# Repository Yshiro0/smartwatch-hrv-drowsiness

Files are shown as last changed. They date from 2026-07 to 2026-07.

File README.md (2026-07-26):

# ESP32-C3 SmartWatch — HR / HRV / Drowsiness Monitor

A wrist-worn drowsiness-detection smartwatch built on the ESP32-C3, paired over BLE with a companion Android app that handles GPS tracking and alerts. Designed as a low-cost fatigue monitor for drivers, students, and shift workers.

  

---

## Overview

The watch continuously reads heart rate, heart-rate variability (HRV), and wrist tilt, then computes a live **0–100 drowsiness score** on-device. Sensor data streams over Bluetooth Low Energy to a phone app every 500 ms; the phone owns GPS/speed and fires a vibration + alarm whenever the score crosses a drowsy threshold.

```
┌─────────────────────────┐        BLE (GATT)        ┌──────────────────────────┐
│   ESP32-C3 Watch         │ ───── sensor JSON ────►  │   Android App             │
│                          │        every 500ms        │                          │
│ • MAX30102 (HR/HRV)      │ ◄──── lat,lng,speed ────  │ • FusedLocationProvider   │
│ • MPU6050 (tilt)         │                            │ • Vibration + alarm       │
│ • GC9A01 round display   │                            │ • Live dashboard UI       │
└─────────────────────────┘                            └──────────────────────────┘
```

**Design decision:** GPS, vibration, and sound alerts live on the *phone*, not the watch. The watch's only job is to sense and stream — this keeps the firmware simple and avoids needing a GPS module or buzzer on the wrist unit.

---

## Features

- Real-time BPM display with animated heartbeat icon and live ECG/PPG-style waveform strip
- HRV (SDNN) computed from the last 8 RR intervals
- Wrist tilt angle from accelerometer, used as a head-drop / posture-change proxy
- Weighted, multi-signal drowsiness score (0–100) with a 3-minute personal calibration phase
- BLE GATT server on the watch — auto re-advertises on disconnect
- Android dashboard: BPM, HRV (with qualitative label), drowsiness %, tilt, GPS lat/lng, speed, calibration progress, alert history
- Drowsiness alert: vibration pattern + alarm tone + toast, with a 15-second cooldown to avoid alert spam
- Finger-presence detection to avoid false readings when the watch isn't worn

---

## Hardware

| Component | Part | Interface |
|---|---|---|
| MCU | ESP32-C3 Super Mini | — |
| Display | GC9A01, 240×240 round SPI | SPI |
| Heart rate / SpO₂ sensor | MAX30102 | I2C (0x57) |
| IMU (tilt) | MPU6050 | I2C (0x68) |

### Wiring

**Display (GC9A01):**

| Display Pin | ESP32-C3 GPIO |
|---|---|
| SCK | GPIO 2 |
| MOSI (SDA) | GPIO 4 |
| CS | GPIO 5 |
| DC | GPIO 1 |
| RST | GPIO 0 |
| BLK | 3.3V (**must be tied high — screen stays blank otherwise**) |

**I2C bus (shared by MAX30102 + MPU6050):**

| Signal | ESP32-C3 GPIO |
|---|---|
| SDA | GPIO 6 |
| SCL | GPIO 7 |

MPU6050's `AD0` pin is tied to GND (address `0x68`). GPIO8/GPIO9 are avoided for I2C since they're strapping pins that can prevent boot if pulled low at startup.

Run the I2C scanner in `firmware/WIRING.md` first — you should see both `0x57` and `0x68` before flashing the main sketch.

---

## Firmware

**Stack:** Arduino IDE (C++) · [Arduino_GFX_Library](https://github.com/moononournation/Arduino_GFX) · SparkFun MAX3010x library · raw I2C driver for MPU6050 · ESP32 BLE Arduino (GATT server)

**Board:** `ESP32C3 Dev Module` or `Nologo ESP32C3 Super Mini`

### Signal processing

- **Beat detection:** adaptive-threshold, rising-edge-only detection on the MAX30102 IR channel (SparkFun `checkForBeat`), gated to accept RR intervals between 400–1500 ms to reject noise
- **HRV (SDNN):** standard deviation of the last 8 RR intervals — the classic time-domain HRV metric
- **Tilt angle:** `θ = arccos(az / |a|)`, where `|a| = sqrt(ax² + ay² + az²)` — the angle between the wrist's Z-axis and vertical
- **Drowsiness score (0–100):** a weighted sum of three components, recomputed every 500 ms once calibration is done:
  - up to **50 pts** for HRV dropping below the personal baseline
  - up to **30 pts** for tilt deviating from the baseline posture (scaled over a 15° range)
  - up to **20 pts** for BPM dropping below 65 (scaled over a 20 bpm–65 bpm range)
- **Calibration:** a 3-minute warm-up on boot averages SDNN and tilt while the wearer is alert and seated, establishing `baselineSDNN` and `baselineTilt` for the scoring formulas above

A full derivation of these formulas, plus expected margin-of-error tables, is in [`docs/HRV_Tilt_Drowsiness_Reference.pdf`](docs/HRV_Tilt_Drowsiness_Reference.pdf).

### Required libraries (Arduino Library Manager)

- `Arduino_GFX_Library` (moononournation)
- `SparkFun MAX3010x Pulse and Proximity Sensor Library`
- `ESP32 BLE Arduino` (bundled with the ESP32 board package)

### Uploading

If the COM port doesn't show up or upload fails: hold **BOOT**, tap **RST**, release **BOOT**, then click Upload.

---

## BLE protocol

The watch advertises as `SmartWatch` and runs a single GATT service:

```
Service UUID:       12345678-1234-1234-1234-123456789abc
Sensor Char UUID:   12345678-1234-1234-1234-123456789abd   Notify · watch → phone
Location Char UUID: 12345678-1234-1234-1234-123456789abe   Write  · phone → watch
```

**Watch → phone** (JSON, sent every 500 ms):

```json
{"b":72,"h":42.1,"d":35.0,"t":8.2,"c":1,"f":1}
```

| Field | Meaning | Type |
|---|---|---|
| `b` | Heart rate (BPM) | int |
| `h` | HRV / SDNN (ms) | float |
| `d` | Drowsiness score (0–100) | float |
| `t` | Tilt angle (degrees) | float |
| `c` | Calibration complete (0/1) | int |
| `f` | Finger detected on sensor (0/1) | int |

**Phone → watch** (plain CSV string, sent on every location update):

```
<lat>,<lng>,<speed_kmh>
```

e.g. `14.083200,121.145600,42.3` — parsed on the watch by splitting on the first and last comma.

---

## Android app

**Stack:** Android Studio, Kotlin, BLE GATT client, Google Play Services `FusedLocationProviderClient`, `minSdk 26` / `targetSdk 34`

**What it does:**
- Scans for and connects to the `SmartWatch` BLE device, subscribes to sensor notifications
- Renders BPM, HRV (with a qualitative label — Very Low / Low / Moderate / Normal / Excellent), drowsiness % with color-coded state (AWAKE / ALERT / DROWSY), tilt, and calibration progress
- Streams GPS lat/lng/speed via `FusedLocationProviderClient` (1s interval, high accuracy) and writes it back to the watch's Location characteristic
- Fires a **vibration pattern + alarm ringtone + toast** when drowsiness score ≥ 70% *and* the finger sensor confirms the watch is being worn, with a 15-second cooldown between alerts
- Tracks alert count and last-alert timestamp for the session

**Permissions required:** `BLUETOOTH_SCAN`, `BLUETOOTH_CONNECT` (Android 12+), `ACCESS_FINE_LOCATION`, `ACCESS_COARSE_LOCATION`, `VIBRATE`.

---

## 3D-printed case & strap

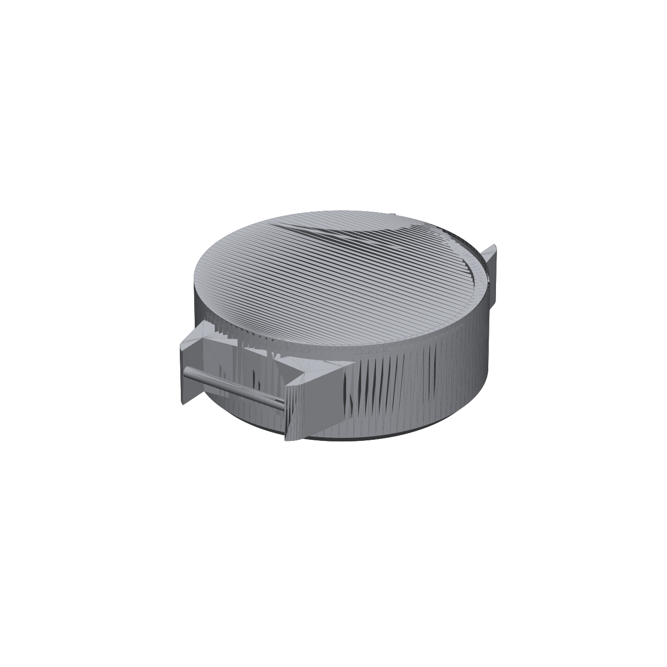
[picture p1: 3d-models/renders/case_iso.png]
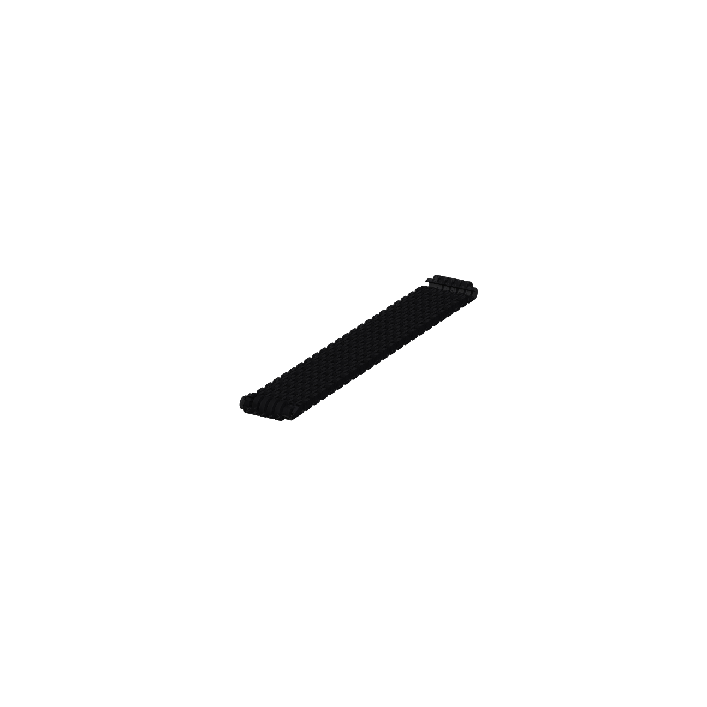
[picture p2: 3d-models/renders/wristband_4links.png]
 

A printable enclosure and modular link wristband are included in [`3d-models/`](3d-models/), along with preview renders and approximate dimensions for each part. See [`3d-models/README.md`](3d-models/README.md) for details.

---

## Getting started

1. Wire up the hardware per the [Hardware](#hardware) section above.
2. Open `firmware/smartwatch.ino` in Arduino IDE, install the required libraries, select the ESP32-C3 board, and flash.
3. Confirm over Serial Monitor (115200 baud) that both `MAX30102 OK` and `MPU6050 OK` print, and that BLE begins advertising as `SmartWatch`.
4. Open `android_app/` in Android Studio, build, and install on a phone running Android 8.0 (API 26) or later — or skip building it yourself and install the pre-built [`releases/app-debug.apk`](releases/app-debug.apk) directly (debug build, so you'll need to allow installs from unknown sources / sideloading).
5. Launch the app, grant Bluetooth + Location permissions, and tap **SCAN** to connect.
6. Wear the watch and hold still for the 3-minute calibration countdown shown on both the watch display and the app before relying on the drowsiness score.

---

## Repository structure

```
.
├── firmware/
│   ├── smartwatch.ino       # Full ESP32-C3 sketch — sensors, display, BLE, algorithms
│   └── WIRING.md            # Pin reference, library list, I2C scanner sketch
├── android_app/
│   └── app/
│       ├── src/main/java/.../MainActivity.kt   # BLE client, GPS, alerts, dashboard logic
│       ├── src/main/res/                        # Layouts, colors, drawables
│       └── build.gradle
├── docs/
│   └── HRV_Tilt_Drowsiness_Reference.pdf   # Formulas, algorithm derivation, error margins
├── releases/
│   └── app-debug.apk                       # Pre-built debug APK, ready to sideload
└── 3d-models/
    ├── watchcase_new.3mf                              # Printable case assembly
    ├── prizma_wristband_144mm_plus4links.stl           # Wristband, larger size
    ├── prizma_wristband_144mm_plus2links.stl           # Wristband, smaller size
    └── renders/                                        # Preview images of the above
```

---

## Known limitations / roadmap

- Drowsiness weighting (50/30/20) was chosen heuristically, not validated against a labeled dataset — treat scores as a relative fatigue indicator, not a clinical measurement
- No on-watch alerting means the wearer relies entirely on the phone being nearby and connected
- Single BLE connection only — no reconnection to a specific phone if multiple are in range
- SDNN over only 8 RR intervals is a short window; longer buffers would give a more stable HRV estimate at the cost of slower response to changes

## License

Add a license of your choice here (MIT is a common default for hobby hardware/firmware projects like this).

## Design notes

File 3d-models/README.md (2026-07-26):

# 3D-Printed Case & Strap

Printable enclosure and wristband for the ESP32-C3 SmartWatch build.

| File | Description | Approx. size (W × L × H, mm) |
|---|---|---|
| [`watchcase_new.3mf`](watchcase_new.3mf) | Watch case assembly — main shell, bezel, and strap lugs | 64 × 80 × 24 |
| [`prizma_wristband_144mm_plus4links.stl`](prizma_wristband_144mm_plus4links.stl) | Modular link wristband, 144mm base + 4 extra links (larger wrist) | 26 × 183 × 8.3 |
| [`prizma_wristband_144mm_plus2links.stl`](prizma_wristband_144mm_plus2links.stl) | Modular link wristband, 144mm base + 2 extra links (smaller wrist) | 26 × 169 × 8.3 |

Dimensions above are bounding-box measurements taken directly from the model files — treat them as a sanity check for build-plate/bed size, not a substitute for checking the actual model in your slicer.

## Case

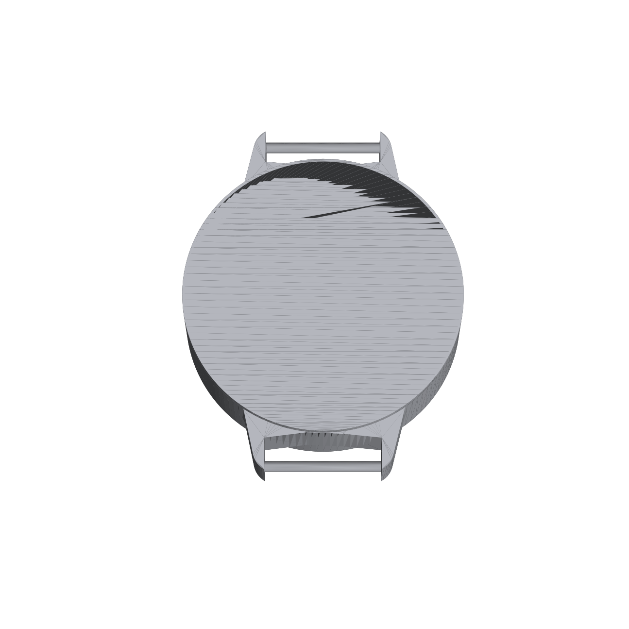
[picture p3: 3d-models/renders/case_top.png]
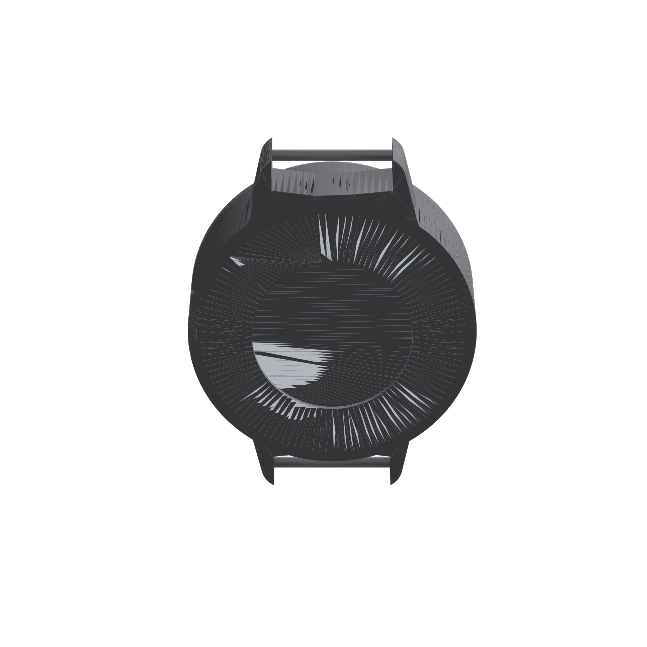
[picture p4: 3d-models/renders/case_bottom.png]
  

Houses the ESP32-C3 Super Mini, GC9A01 round display, MAX30102, and MPU6050 as a single wrist-worn unit. `watchcase_new.3mf` contains the full multi-body assembly (shell + bezel + button/lug details) with parts already positioned — most slicers will preserve the layout on import.

## Wristband

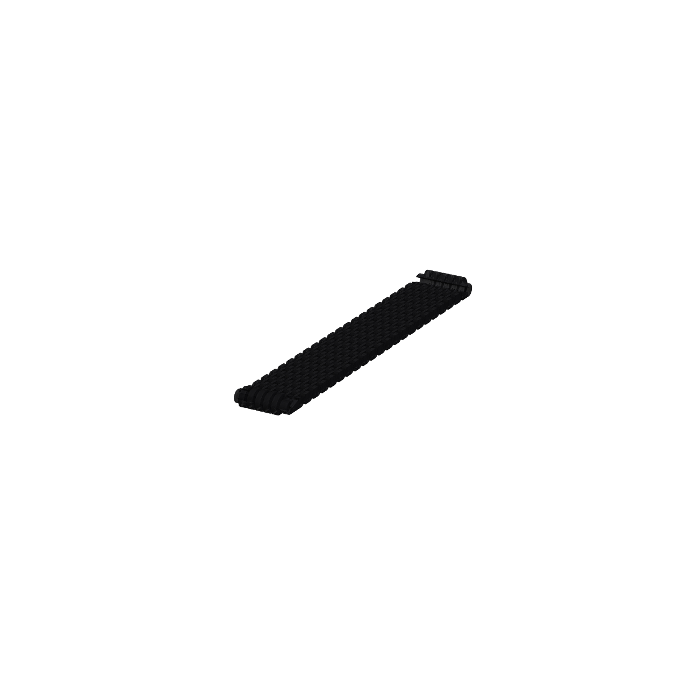
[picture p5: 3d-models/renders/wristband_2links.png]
 

Modular, link-style band that attaches to the case lugs. Two link-count variants are provided so you can pick the closer fit for your wrist size, rather than needing a separate buckle/adjustment mechanism.

## Notes

- Renders above are auto-generated flat-shaded previews for a quick visual reference — they're not a substitute for opening the files in your slicer to check wall thickness, supports, and orientation.
- Recommended print settings (material, layer height, infill, supports) aren't documented yet — add them here once you've dialed in your printer profile.

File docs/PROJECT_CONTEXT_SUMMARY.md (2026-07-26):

# SmartWatch Project — Context Summary

Paste this as your first message in the new account to bring Claude up to speed.

## Project: ESP32-C3 Smartwatch (Heart Rate + HRV + Drowsiness + GPS)

### Hardware
- ESP32-C3 Super Mini (MCU)
- GC9A01 240×240 round SPI display — DC=GPIO1, CS=GPIO5, SCK=GPIO2, MOSI=GPIO4, RST=GPIO0, BLK→3.3V
- MAX30102 (heart rate/HRV) — I2C, SDA=GPIO6, SCL=GPIO7, addr 0x57
- MPU6050 (accel/gyro, tilt) — I2C same bus, addr 0x68

### Firmware stack
Arduino IDE, C++, Arduino_GFX_Library, SparkFun MAX3010x library,
raw I2C for MPU6050, ESP32 BLE Arduino (GATT server)

### Key algorithms implemented
- Median filter + IIR low-pass on heart signal
- Adaptive threshold beat detection (envelope tracking, rising-edge only)
- SDNN (HRV) from last 8 RR intervals
- Tilt angle via arccos(az/|a|) from accelerometer
- Weighted drowsiness score: HRV drop (50pts) + tilt deviation (30pts) + low BPM (20pts) = 0–100 score
- 3-minute calibration phase to set personal baseline SDNN/tilt

### Design decision
GPS, vibration, and sound alerts moved OFF the watch — phone handles these
via BLE instead (watch just streams sensor data, phone does alerts + GPS).

### Mobile app
Android Studio, Kotlin, BLE GATT client, Google Play Services
FusedLocationProviderClient for GPS, min SDK 26. App shows BPM/HRV/drowsiness/
tilt/GPS/speed dashboard and triggers vibrate+alarm when drowsiness >= 70%.

### BLE contract
```
Service UUID:       12345678-1234-1234-1234-123456789abc
Sensor Char UUID:   12345678-1234-1234-1234-123456789abd  (Notify, watch->phone)
Location Char UUID: 12345678-1234-1234-1234-123456789abe  (Write, phone->watch)
```

JSON payload sent from watch to phone every 500ms:
```json
{"b":72,"h":42.1,"d":35.0,"t":8.2,"c":1,"f":1}
```
- b = BPM
- h = HRV (SDNN in ms)
- d = drowsiness score (0-100)
- t = tilt angle (degrees)
- c = calibrated (0/1)
- f = finger detected (0/1)

### Deliverables already created (included in this export)
- `firmware/smartwatch.ino` — full working ESP32-C3 sketch
- `firmware/WIRING.md` — pin reference and required libraries
- `android_app/` — full Android Studio Kotlin project (MainActivity.kt,
  layouts, manifest, gradle files)
- `docs/HRV_Tilt_Drowsiness_Reference.pdf` — technical reference covering
  HRV formulas, tilt formula, drowsiness algorithm, and margin of error

### Current status
Full firmware sketch and full Android Kotlin app both written and working.
Last debugging issue was a blank display (fixed — was too-dark background
colors + wrong pins for wrong board assumption; corrected once confirmed
board is ESP32-C3 Super Mini, not a Waveshare board). Both MAX30102 and
MPU6050 sensors confirmed working via I2C scanner test.

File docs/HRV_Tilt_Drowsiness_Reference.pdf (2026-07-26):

# SmartWatch Technical Reference

### HRV Formulas · Gyroscope Tilt · Drowsiness Detection Algorithm · Margin of Error

This document provides the mathematical foundations, signal processing formulas, detection algorithm, and expected accuracy margins for the physiological monitoring system implemented on the ESP32-S3 smartwatch platform.

## 1. Heart Rate Variability (HRV) — Formulas

Heart Rate Variability (HRV) measures the variation in time between consecutive heartbeats, called RR intervals (or NN intervals when referring to normal-to-normal beats). A higher HRV generally indicates a healthy, responsive autonomic nervous system. Drowsiness and fatigue suppress HRV.

### 1.1 RR Interval

The RR interval is the time (in milliseconds) between two successive R-peaks in the ECG/PPG signal — i.e., two consecutive heartbeats.
RR[i] = t[i] − t[i−1] (milliseconds)

where t[i] is the timestamp of the i-th detected beat peak.

### 1.2 Mean RR (Average Interval)

RR_mean = (1/N) × Σ RR[i] for i = 1 to N

N = number of RR intervals in the analysis window (we use N = 20).

### 1.3 SDNN — Standard Deviation of NN Intervals

SDNN is the primary HRV metric implemented in the system. It reflects overall autonomic variability. Normal awake adults: 50–100 ms. Drowsy/fatigued: typically < 30 ms.
SDNN = sqrt[ (1/N) × Σ (RR[i] − RR_mean)² ]

Expanded step-by-step:

1. Collect last N RR intervals: RR[1], RR[2], ..., RR[N] 2. mean = (RR[1] + RR[2] + ... + RR[N]) / N 3. For each i: diff[i] = RR[i] - mean 4. variance = (diff[1]^2 + diff[2]^2 + ... + diff[N]^2) / N 5. SDNN = sqrt(variance) [result in milliseconds]

### 1.4 RMSSD — Root Mean Square of Successive Differences

RMSSD reflects short-term parasympathetic activity. Not currently displayed but can be added as a secondary metric.
RMSSD = sqrt[ (1/(N−1)) × Σ (RR[i+1] − RR[i])² ] for i = 1 to N−1

### 1.5 SDNN Clinical Reference Ranges

SDNN Range (ms) | Interpretation | Drowsiness Risk
> 100 ms | Excellent HRV — fully alert, healthy ANS | Very Low
50 – 100 ms | Normal awake adult range | Low

30 – 50 ms | Mild fatigue or reduced vigilance | Moderate
< 30 ms | Significant HRV suppression — fatigue/drowsiness | High
< 15 ms | Severe suppression — likely drowsy or sensor error | Very High

Table 1. SDNN clinical reference ranges for drowsiness assessment.

## 2. Gyroscope / Accelerometer Tilt Formula

Tilt angle is computed from the QMI8658C accelerometer axes, not the gyroscope. The accelerometer measures gravitational pull along each axis; when the wrist tilts (as in a drowsy head-drop gesture), the Z-axis component changes relative to total acceleration magnitude.

### 2.1 Total Acceleration Magnitude

|a| = sqrt( ax² + ay² + az² ) [in g-units]
where ax, ay, az are the accelerometer readings on each axis in g. When stationary, |a| ≈ 1.0 g (Earth's gravity).

### 2.2 Tilt Angle from Vertical

The angle θ between the device's Z-axis and vertical (gravity vector) is computed using the inverse cosine of the normalized Z component:
θ = arccos( az / |a| ) [result in radians, convert to degrees]

θ_deg = θ × (180 / π)

In C++ (Arduino) implementation:

float mag = sqrt(ax*ax + ay*ay + az*az); float tiltAngle = degrees( acos( constrain(az / mag, -1.0f, 1.0f) ) );
Note: constrain() clamps the argument of arccos to [−1, +1] to prevent NaN from floating-point rounding errors when az ≈ |a|.

### 2.3 Tilt Angle Interpretation

θ (degrees) | Physical Meaning | Drowsiness Signal
0° – 10° | Device level / wrist flat upright | None
10° – 20° | Slight wrist tilt — normal movement | Baseline variation
20° – 35° | Noticeable wrist drop | Mild (monitor)
35° – 55° | Significant forward head/wrist drop | Moderate alert
> 55° | Severe tilt — possible nodding off | Strong alert

Table 2. Tilt angle interpretation for wrist-worn device.

### 2.4 Tilt Deviation from Baseline

Because individuals naturally hold their wrist at different resting angles, absolute tilt is less meaningful than deviation from the calibrated baseline:
∆Tilt = | θ_current − θ_baseline | [degrees]

θ_baseline is measured and averaged over the 3-minute calibration window. ∆Tilt > 15° triggers a partial drowsiness score contribution.

## 3. Drowsiness Detection Algorithm

The system uses a weighted multi-modal scoring algorithm combining three physiological signals. A composite drowsiness score D (0–100) is computed every 500 ms after the calibration phase completes.

### 3.1 Calibration Phase (0 – 3 minutes)

Before drowsiness detection begins, the system runs a 3-minute (180-second) calibration window to establish the user's personal baseline. During this window:

For each detected heartbeat during calibration: — Record RR interval — Compute running SDNN — Record current tilt angle At end of 180 seconds: baselineSDNN = average of all SDNN samples collected baselineTilt = average of all tilt angle samples collected
Note: Calibration must be performed while the user is alert and in a normal seated/standing posture. Results are invalid if calibrated while already fatigued.

### 3.2 Composite Drowsiness Score Formula

Three sub-scores are computed and summed:

Sub-score 1 — HRV Drop Score (0 to 50 points):
S_hrv = max( 0, ((baselineSDNN − SDNN_current) / baselineSDNN) × 50 )

S_hrv = 0 when SDNN ≥ baseline (alert). S_hrv = 50 when SDNN = 0 (maximum suppression).

Sub-score 2 — Tilt Deviation Score (0 to 30 points):
S_tilt = min( 30, (∆Tilt / 15°) × 30 )

S_tilt = 0 when ∆Tilt = 0°. S_tilt = 30 when ∆Tilt ≥ 15°.

Sub-score 3 — Low Heart Rate Score (0 to 20 points):
S_bpm = min( 20, ((65 − BPM_current) / 20) × 20 ) if BPM < 65

S_bpm = 0 if BPM ≥ 65

Drowsiness tends to lower heart rate slightly. Threshold is 65 BPM; maximum contribution at 45 BPM or below.

Total Composite Score:

D = clamp( S_hrv + S_tilt + S_bpm, 0, 100 )

### 3.3 Decision Thresholds

Score D | State | Display Color | Action
0 – 39 | AWAKE | Green | No action
40 – 69 | ALERT | Amber | Caution — monitor closely
70 – 100 | DROWSY! | Red | Alert caregiver / vibrate

Table 3. Drowsiness score decision thresholds.

### 3.4 Algorithm Flowchart (Text Form)

START | ■■ [Calibration phase — 180s] | Collect SDNN samples → compute baselineSDNN |
Collect tilt samples → compute baselineTilt | ■■ [Detection phase — every 500ms] Read
current BPM, SDNN, tiltAngle Compute S_hrv = max(0, ((baselineSDNN - SDNN) / baselineSDNN) *
50) Compute S_tilt = min(30, (|tiltAngle - baselineTilt| / 15) * 30) Compute S_bpm = (BPM <
65) ? min(20, ((65-BPM)/20)*20) : 0 D = clamp(S_hrv + S_tilt + S_bpm, 0, 100) IF D < 40 → AWAKE (green) IF D < 70 → ALERT (amber) IF D >= 70 → DROWSY (red) → trigger alert END LOOP

## 4. Margin of Error — Sensors and Derived Metrics

All sensor readings carry inherent measurement uncertainty. The values below reflect expected accuracy for the specific hardware used in this system (MAX30102 pulse oximeter, QMI8658C IMU, analog PPG sensor on GPIO0).

### 4.1 Heart Rate (BPM) Accuracy

Source | Error / Uncertainty
Analog PPG (GPIO0) — raw ADC noise | ±3–5 BPM at rest
After median + IIR filter | ±2–3 BPM at rest
Motion artifact (wrist movement) | ±5–15 BPM during movement
Adaptive threshold drift | ±1–2 BPM
Overall expected accuracy (still, correct placement) | ±2–3 BPM
Clinical-grade reference (MAX30102) | ±1 BPM (per datasheet)

Table 4. Heart rate measurement error sources.

### 4.2 HRV (SDNN) Accuracy

Source | Error / Uncertainty
Timing resolution (millis() @ 1ms tick) | ±1 ms per RR interval
Beat detection jitter (peak threshold) | ±5–10 ms per RR interval
Accumulated error over N=20 intervals | ±3–8 ms on SDNN value
Motion artifact false beats | ±10–20 ms SDNN during movement
Overall SDNN error at rest | ±5–10 ms (acceptable for drowsiness)
Minimum detectable SDNN change | ~5 ms

Table 5. HRV (SDNN) measurement error sources.

### 4.3 Gyroscope / Accelerometer (Tilt) Accuracy

Source | Error / Uncertainty
QMI8658C accelerometer noise density | ±0.07 mg/√Hz
QMI8658C zero-g offset (factory) | ±20 mg typical
Tilt angle error at rest (computed) | ±0.5° – 1.5°
Tilt angle error during slow movement | ±2° – 5°
Vibration / rapid motion artifact | ±5° – 15° transient
Temperature drift (no compensation) | ±0.1° per °C change
Overall tilt accuracy (slow movement) | ±1° – 3°

Minimum detectable tilt change | ~1°

Table 6. QMI8658C tilt angle error sources.

### 4.4 Drowsiness Score Accuracy

Because the drowsiness score D is derived from three noisy signals, its uncertainty is the propagated combination of all sub-score errors:
σ_D ≈ sqrt( σ_hrv_score² + σ_tilt_score² + σ_bpm_score² )

In practice, with sensors at rest and correct placement:

Sub-score | Typical Error Contribution
S_hrv (HRV drop, max 50 pts) | ±3 – 6 points
S_tilt (Tilt deviation, max 30 pts) | ±1 – 4 points
S_bpm (Low BPM, max 20 pts) | ±1 – 2 points
Total D (0–100 scale) | ±4 – 8 points overall

Table 7. Propagated drowsiness score uncertainty.

Note: A score margin of ±8 points means the system cannot reliably distinguish D=40 from D=48. The 40/70 thresholds include an implicit safety margin to account for this. For clinical applications, validation against polysomnography (PSG) reference is recommended.

ESP32-S3 Wearable Platform | For academic and prototype use only. Not a certified medical device.

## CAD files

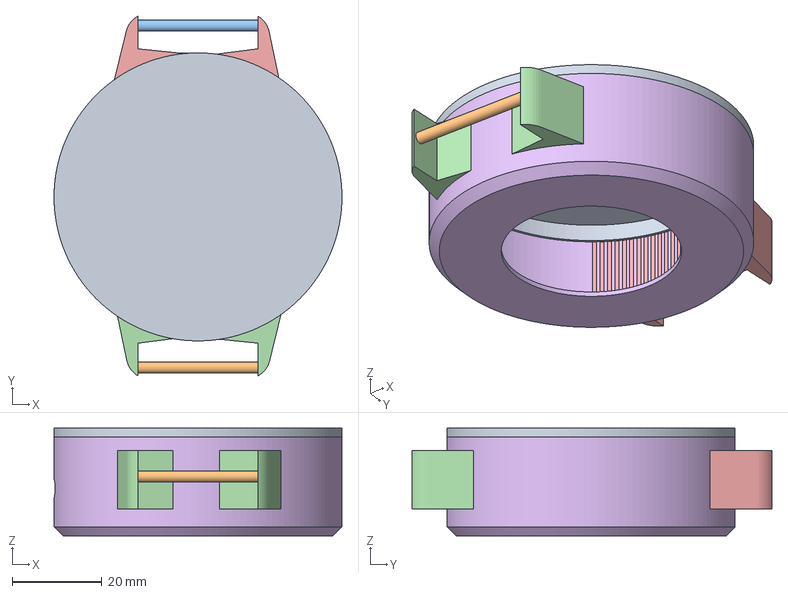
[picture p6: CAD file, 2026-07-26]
3d-models/watchcase_new.3mf
64.0 x 80.0 x 24.0 mm

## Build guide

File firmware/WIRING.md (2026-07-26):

# Wiring Reference — ESP32-C3 Super Mini Smartwatch

## Display (GC9A01 240x240 round SPI)

| Display Pin | ESP32-C3 GPIO |
|---|---|
| SCL (CLK) | GPIO 2 |
| SDA (MOSI) | GPIO 4 |
| CS | GPIO 5 |
| DC | GPIO 1 |
| RST | GPIO 0 |
| VCC | 3.3V |
| GND | GND |
| BLK | 3.3V (backlight always on — REQUIRED or screen stays blank) |

## I2C Bus (shared by MAX30102 + MPU6050)

| Sensor Pin | ESP32-C3 GPIO |
|---|---|
| SDA | GPIO 6 |
| SCL | GPIO 7 |

Avoid GPIO8/GPIO9 for I2C — they are strapping pins and can prevent boot if pulled low during startup.

### MAX30102 (Heart Rate / HRV)
- VIN → 3.3V
- GND → GND
- SDA → GPIO 6
- SCL → GPIO 7
- I2C Address: 0x57

### MPU6050 (Accelerometer / Gyroscope / Tilt)
- VCC → 3.3V (NOT 5V)
- GND → GND
- SDA → GPIO 6 (same wire as MAX30102)
- SCL → GPIO 7 (same wire as MAX30102)
- AD0 → GND (sets address to 0x68)
- I2C Address: 0x68

## Required Libraries (Arduino IDE Library Manager)
- Arduino_GFX_Library (moononournation)
- SparkFun MAX3010x Pulse and Proximity Sensor Library
- ESP32 BLE Arduino (bundled with ESP32 board package)

## Board Selection
- Board: "ESP32C3 Dev Module" or "Nologo ESP32C3 Super Mini"

## Uploading (if COM port errors occur)
1. Hold BOOT button
2. Press and release RST
3. Release BOOT
4. Click Upload

## I2C Scanner (run first to verify wiring)
```cpp
#include <Wire.h>
void setup() {
  Serial.begin(115200);
  delay(1000);
  Wire.begin(6, 7);
  Serial.println("Scanning I2C...");
  for (byte addr = 1; addr < 127; addr++) {
    Wire.beginTransmission(addr);
    if (Wire.endTransmission() == 0) {
      Serial.print("Found device at 0x");
      Serial.println(addr, HEX);
    }
  }
}
void loop() {}
```
Expect to see 0x57 (MAX30102) and 0x68 (MPU6050).

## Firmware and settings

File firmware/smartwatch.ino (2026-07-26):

#include <Arduino_GFX_Library.h>
#include <Wire.h>
#include <BLEDevice.h>
#include <BLEServer.h>
#include <BLEUtils.h>
#include <BLE2902.h>
#include "MAX30105.h"
#include "heartRate.h"

// ─── Colors ───────────────────────────────────────────────────────────────────
#define BLACK    0x0000
#define WHITE    0xFFFF
#define GRAY     0x8410
#define DARKGRAY 0x2104
#define CRIMSON  0xF82E
#define GREEN    0x07E6
#define AMBER    0xF7E0
#define CYAN     0x4F9F
#define PURPLE   0x981F
#define ORANGE   0xFC80

// ─── Display pins (ESP32-C3 Super Mini + GC9A01) ─────────────────────────────
Arduino_DataBus *bus = new Arduino_ESP32SPI(1, 5, 2, 4, -1);
Arduino_GFX    *gfx = new Arduino_GC9A01(bus, 0, 0, true);
#define CX 120

// ─── I2C (shared bus for MAX30102 + MPU6050) ─────────────────────────────────
#define SDA_PIN 6
#define SCL_PIN 7

// ─── MAX30102 ─────────────────────────────────────────────────────────────────
MAX30105 particleSensor;

#define RATE_SIZE 8
uint32_t rrIntervals[RATE_SIZE] = {};
byte     rateSpot    = 0;
long     lastBeat    = 0;
int      bpm         = 0;
bool     fingerOn    = false;

float sdnn = 0;

// ─── MPU6050 ──────────────────────────────────────────────────────────────────
#define MPU_ADDR 0x68
float tiltAngle = 0;
float accelMag  = 0;
unsigned long lastImuUpdate = 0;

void mpuInit() {
  Wire.beginTransmission(MPU_ADDR);
  Wire.write(0x6B); Wire.write(0);    // wake
  Wire.endTransmission();
  Wire.beginTransmission(MPU_ADDR);
  Wire.write(0x1C); Wire.write(0x08); // ±4g
  Wire.endTransmission();
}

bool mpuRead(float &ax, float &ay, float &az) {
  Wire.beginTransmission(MPU_ADDR);
  Wire.write(0x3B);
  if (Wire.endTransmission(false) != 0) return false;
  Wire.requestFrom(MPU_ADDR, 6);
  if (Wire.available() < 6) return false;
  int16_t rx = (Wire.read()<<8)|Wire.read();
  int16_t ry = (Wire.read()<<8)|Wire.read();
  int16_t rz = (Wire.read()<<8)|Wire.read();
  ax = rx / 8192.0f;
  ay = ry / 8192.0f;
  az = rz / 8192.0f;
  return true;
}

// ─── Calibration (3 minutes) ─────────────────────────────────────────────────
#define CALIB_MS 180000UL
bool  calibDone      = false;
unsigned long calibStart = 0;
float baselineSDNN   = 0;
float baselineTilt   = 0;
int   calibSamples   = 0;
float calibSDNNSum   = 0;
float calibTiltSum   = 0;

// ─── Drowsiness ───────────────────────────────────────────────────────────────
float drowsinessScore    = 0;
unsigned long lastDrowsyUpdate = 0;

// ─── BLE ──────────────────────────────────────────────────────────────────────
#define SERVICE_UUID       "12345678-1234-1234-1234-123456789abc"
#define CHAR_SENSOR_UUID   "12345678-1234-1234-1234-123456789abd"
#define CHAR_LOCATION_UUID "12345678-1234-1234-1234-123456789abe"

BLEServer         *pServer      = nullptr;
BLECharacteristic *pSensorChar  = nullptr;
BLECharacteristic *pLocationChar = nullptr;
bool deviceConnected = false;
bool oldConnected    = false;
unsigned long lastBLESend = 0;

float phoneLat = 0, phoneLng = 0, phoneSpeed = 0;

class ServerCallbacks : public BLEServerCallbacks {
  void onConnect(BLEServer *s)    override { deviceConnected = true;  }
  void onDisconnect(BLEServer *s) override { deviceConnected = false; }
};

class LocationCallbacks : public BLECharacteristicCallbacks {
  void onWrite(BLECharacteristic *c) override {
    String val = c->getValue().c_str();
    int c1 = val.indexOf(',');
    int c2 = val.lastIndexOf(',');
    if (c1 > 0 && c2 > c1) {
      phoneLat   = val.substring(0, c1).toFloat();
      phoneLng   = val.substring(c1+1, c2).toFloat();
      phoneSpeed = val.substring(c2+1).toFloat();
    }
  }
};

// ─── ECG strip ────────────────────────────────────────────────────────────────
const int ECG_X0  = 14, ECG_X1 = 226;
const int ECG_Y0  = 120, ECG_H  = 22;
const int ECG_CY  = ECG_Y0 + ECG_H / 2;
const int ECG_AMP = 9;
int ecgX = 0;

// ─── Heart animation ──────────────────────────────────────────────────────────
bool heartBig = false;
unsigned long lastHeartPulse = 0;

// ─── Misc timing ──────────────────────────────────────────────────────────────
unsigned long lastDisplayUpdate = 0;

// ─────────────────────────────────────────────────────────────────────────────
// HRV — SDNN from RR intervals
// ─────────────────────────────────────────────────────────────────────────────
float calcSDNN() {
  int count = 0;
  for (int i = 0; i < RATE_SIZE; i++) if (rrIntervals[i] > 0) count++;
  if (count < 2) return 0;
  float mean = 0;
  for (int i = 0; i < RATE_SIZE; i++) mean += rrIntervals[i];
  mean /= count;
  float var = 0;
  for (int i = 0; i < count; i++) {
    float d = rrIntervals[i] - mean;
    var += d * d;
  }
  return sqrt(var / count);
}

// ─────────────────────────────────────────────────────────────────────────────
// Drowsiness score
// ─────────────────────────────────────────────────────────────────────────────
void computeDrowsiness() {
  if (!calibDone) { drowsinessScore = 0; return; }
  float s_hrv  = (baselineSDNN > 0 && sdnn < baselineSDNN)
                 ? ((baselineSDNN - sdnn) / baselineSDNN) * 50.0f : 0;
  float s_tilt = constrain((fabsf(tiltAngle - baselineTilt) / 15.0f) * 30.0f, 0, 30);
  float s_bpm  = (bpm > 0 && bpm < 65)
                 ? constrain(((65 - bpm) / 20.0f) * 20.0f, 0, 20) : 0;
  drowsinessScore = constrain(s_hrv + s_tilt + s_bpm, 0, 100);
}

// ─────────────────────────────────────────────────────────────────────────────
// Display helpers
// ─────────────────────────────────────────────────────────────────────────────
void drawHeart(int cx, int cy, int s, uint16_t col) {
  gfx->fillCircle(cx-s/2, cy-s/4, s/2, col);
  gfx->fillCircle(cx+s/2, cy-s/4, s/2, col);
  gfx->fillRect(cx-s+1, cy-s/4, (s-1)*2, s/2, col);
  gfx->fillTriangle(cx-s,cy+s/4, cx,cy+s+s/2, cx,cy+s/4, col);
  gfx->fillTriangle(cx+s,cy+s/4, cx,cy+s+s/2, cx,cy+s/4, col);
}

void drawStaticFrame() {
  gfx->setTextSize(1);
  gfx->setTextColor(GRAY);
  gfx->setCursor(62, 8);
  gfx->print("HEART  RATE");

  gfx->fillRoundRect(ECG_X0, ECG_Y0, ECG_X1-ECG_X0, ECG_H, 3, 0x02A0);

  gfx->fillRoundRect(8, 148, 106, 20, 4, 0x1001);
  gfx->setTextColor(PURPLE);
  gfx->setCursor(14, 153); gfx->print("HRV:");

  gfx->fillRoundRect(120, 148, 112, 20, 4, 0x2000);
  gfx->setTextColor(ORANGE);
  gfx->setCursor(126, 153); gfx->print("DROWSY:");

  gfx->fillRoundRect(8, 172, 110, 52, 4, 0x0010);
  gfx->setTextColor(CYAN);
  gfx->setCursor(46, 175); gfx->print("GPS");
  gfx->setTextColor(GRAY);
  gfx->setCursor(14, 190); gfx->print("LAT");
  gfx->setCursor(14, 202); gfx->print("LNG");
  gfx->setCursor(14, 214); gfx->print("SPD");

  gfx->fillRoundRect(122, 172, 110, 52, 4, 0x2000);
  gfx->setTextColor(AMBER);
  gfx->setCursor(152, 175); gfx->print("SPEED");
  gfx->setCursor(158, 214); gfx->print("KM/H");

  // BLE dot
  gfx->fillCircle(CX, 234, 4, DARKGRAY);
}

void drawBPM(int v) {
  gfx->fillRect(CX-40, 22, 80, 34, BLACK);
  char buf[8];
  snprintf(buf, sizeof(buf), "%d", v > 0 ? v : 0);
  int w = strlen(buf) * 6 * 4;
  gfx->setCursor(CX - w/2, 22);
  gfx->setTextColor(v > 0 ? WHITE : GRAY);
  gfx->setTextSize(4);
  gfx->print(buf);
}

void drawHeartAnim() {
  gfx->fillRect(CX-36, 58, 76, 20, BLACK);
  gfx->setTextColor(CRIMSON);
  gfx->setTextSize(1);
  gfx->setCursor(CX-34, 64);
  gfx->print("BPM");
  drawHeart(CX+20, 64, heartBig ? 9 : 6, CRIMSON);
}

void drawECGSample(long irRaw) {
  int screenX = ECG_X0 + ecgX;
  gfx->drawFastVLine(screenX, ECG_Y0, ECG_H, 0x02A0);
  int ahead = (screenX+3 < ECG_X1) ? screenX+3 : ECG_X0;
  gfx->drawFastVLine(ahead, ECG_Y0, ECG_H, DARKGRAY);

  long irClamped = constrain(irRaw, 50000, 150000);
  int y = constrain(ECG_CY - map(irClamped, 50000, 150000, -ECG_AMP, ECG_AMP),
                    ECG_Y0, ECG_Y0 + ECG_H - 1);
  gfx->drawFastVLine(screenX, y-1, 3, fingerOn ? GREEN : DARKGRAY);
  if (++ecgX >= ECG_X1 - ECG_X0) ecgX = 0;
}

void drawHRV(float v) {
  gfx->fillRect(50, 150, 60, 14, 0x1001);
  char buf[10];
  snprintf(buf, sizeof(buf), "%.0fms", v);
  gfx->setTextColor(WHITE);
  gfx->setTextSize(1);
  gfx->setCursor(52, 153);
  gfx->print(v > 0 ? buf : "--ms");
}

void drawDrowsy(float score) {
  gfx->fillRect(178, 150, 50, 14, 0x2000);
  char buf[8];
  snprintf(buf, sizeof(buf), "%.0f%%", score);
  uint16_t col = score > 70 ? CRIMSON : (score > 40 ? AMBER : GREEN);
  gfx->setTextColor(col);
  gfx->setTextSize(1);
  gfx->setCursor(180, 153);
  gfx->print(calibDone ? buf : "CAL..");
}

void drawGPS(float lat, float lng, float spd) {
  gfx->fillRect(40, 189, 74, 30, 0x0010);
  gfx->setTextSize(1);
  if (lat != 0 && lng != 0) {
    char la[12], ln[12];
    dtostrf(lat, 7, 4, la);
    dtostrf(lng, 7, 4, ln);
    gfx->setTextColor(WHITE);
    gfx->setCursor(40, 190); gfx->print(la);
    gfx->setCursor(40, 202); gfx->print(ln);
  } else {
    gfx->setTextColor(GRAY);
    gfx->setCursor(40, 190); gfx->print("no phone");
    gfx->setCursor(40, 202); gfx->print("GPS yet");
  }
  gfx->fillRect(40, 213, 74, 8, 0x0010);
  gfx->setTextColor(AMBER);
  gfx->setCursor(40, 214);
  char sb[8]; snprintf(sb, sizeof(sb), "%.1f", spd);
  gfx->print(sb);
}

void drawSpeed(float spd) {
  gfx->fillRect(130, 190, 98, 22, 0x2000);
  char buf[6];
  snprintf(buf, sizeof(buf), "%.0f", spd);
  int sw = strlen(buf) * 6 * 2;
  gfx->setCursor(177 - sw/2, 192);
  gfx->setTextColor(WHITE);
  gfx->setTextSize(2);
  gfx->print(buf);
}

void drawCalibBar(unsigned long now) {
  gfx->fillRoundRect(30, 229, 178, 10, 2, 0x1082);
  if (calibDone) {
    gfx->setTextColor(GREEN); gfx->setTextSize(1);
    gfx->setCursor(52, 230); gfx->print("CALIBRATED");
    return;
  }
  unsigned long elapsed = now - calibStart;
  int pct = constrain((int)((elapsed * 100UL) / CALIB_MS), 0, 100);
  if (pct > 0) gfx->fillRect(30, 229, pct * 178 / 100, 10, AMBER);
  char buf[20];
  snprintf(buf, sizeof(buf), "CAL %d%%", pct);
  gfx->setTextColor(BLACK); gfx->setTextSize(1);
  gfx->setCursor(34, 230); gfx->print(buf);
}

void drawBLEStatus(bool connected) {
  gfx->fillCircle(CX, 234, 4, connected ? GREEN : DARKGRAY);
}

void drawFingerStatus() {
  gfx->fillRect(CX-28, 78, 56, 8, BLACK);
  gfx->setTextSize(1);
  if (!fingerOn) {
    gfx->setTextColor(GRAY);
    gfx->setCursor(CX-28, 78);
    gfx->print("no finger");
  }
}

// ─────────────────────────────────────────────────────────────────────────────
void setup() {
  Serial.begin(115200);

  // Display
  gfx->begin();
  gfx->fillScreen(BLACK);
  delay(100);
  drawStaticFrame();
  drawBPM(0);
  drawHeartAnim();
  drawHRV(0);
  drawDrowsy(0);
  drawGPS(0, 0, 0);
  drawSpeed(0);

  // I2C — both sensors share same bus
  Wire.begin(SDA_PIN, SCL_PIN);

  // MPU6050
  mpuInit();
  Serial.println("MPU6050 OK");

  // MAX30102
  if (!particleSensor.begin(Wire, I2C_SPEED_FAST)) {
    Serial.println("MAX30102 not found!");
  } else {
    Serial.println("MAX30102 OK");
    particleSensor.setup();
    particleSensor.setPulseAmplitudeRed(0x1F);
    particleSensor.setPulseAmplitudeIR(0x1F);
    particleSensor.setPulseAmplitudeGreen(0);
  }

  // BLE
  BLEDevice::init("SmartWatch");
  pServer = BLEDevice::createServer();
  pServer->setCallbacks(new ServerCallbacks());

  BLEService *pService = pServer->createService(SERVICE_UUID);

  pSensorChar = pService->createCharacteristic(
    CHAR_SENSOR_UUID, BLECharacteristic::PROPERTY_NOTIFY);
  pSensorChar->addDescriptor(new BLE2902());

  pLocationChar = pService->createCharacteristic(
    CHAR_LOCATION_UUID, BLECharacteristic::PROPERTY_WRITE);
  pLocationChar->setCallbacks(new LocationCallbacks());

  pService->start();
  BLEAdvertising *pAdv = BLEDevice::getAdvertising();
  pAdv->addServiceUUID(SERVICE_UUID);
  pAdv->setScanResponse(true);
  BLEDevice::startAdvertising();
  Serial.println("BLE advertising as 'SmartWatch'");

  calibStart = millis();
}

// ─────────────────────────────────────────────────────────────────────────────
void loop() {
  unsigned long now = millis();

  // ── BLE reconnect ─────────────────────────────────────────────────────────
  if (!deviceConnected && oldConnected) {
    delay(300);
    pServer->startAdvertising();
    oldConnected = false;
    drawBLEStatus(false);
  }
  if (deviceConnected && !oldConnected) {
    oldConnected = true;
    drawBLEStatus(true);
  }

  // ── MPU6050 @ 25Hz ────────────────────────────────────────────────────────
  if (now - lastImuUpdate >= 40) {
    lastImuUpdate = now;
    float ax, ay, az;
    if (mpuRead(ax, ay, az)) {
      float mag = sqrt(ax*ax + ay*ay + az*az);
      if (mag > 0) {
        tiltAngle = degrees(acos(constrain(az/mag, -1.0f, 1.0f)));
        accelMag  = fabsf(mag - 1.0f) * 9.81f;
      }
    }
  }

  // ── MAX30102 — read IR and detect beats ───────────────────────────────────
  long irValue = particleSensor.getIR();
  fingerOn = (irValue > 50000);

  if (fingerOn) {
    if (checkForBeat(irValue)) {
      long delta = now - lastBeat;
      lastBeat = now;

      if (delta > 400 && delta < 1500) {
        rrIntervals[rateSpot] = delta;
        rateSpot = (rateSpot + 1) % RATE_SIZE;

        float sum = 0; int cnt = 0;
        for (int i = 0; i < RATE_SIZE; i++) {
          if (rrIntervals[i] > 0) { sum += rrIntervals[i]; cnt++; }
        }
        if (cnt > 0) bpm = (int)(60000.0f / (sum / cnt));

        sdnn = calcSDNN();

        if (!calibDone && sdnn > 0) {
          calibSDNNSum += sdnn;
          calibTiltSum += tiltAngle;
          calibSamples++;
        }

        heartBig = true;
        lastHeartPulse = now;
      }
    }
  } else {
    bpm = 0;
    memset(rrIntervals, 0, sizeof(rrIntervals));
    rateSpot = 0;
    sdnn = 0;
  }

  // ── Calibration completion ────────────────────────────────────────────────
  if (!calibDone && now - calibStart >= CALIB_MS) {
    calibDone = true;
    if (calibSamples > 0) {
      baselineSDNN = calibSDNNSum / calibSamples;
      baselineTilt = calibTiltSum / calibSamples;
    }
    Serial.printf("Calibrated: SDNN=%.1f Tilt=%.1f\n", baselineSDNN, baselineTilt);
  }

  // ── Drowsiness @ 500ms ────────────────────────────────────────────────────
  if (now - lastDrowsyUpdate >= 500) {
    lastDrowsyUpdate = now;
    computeDrowsiness();
  }

  // ── Heart animation timing ────────────────────────────────────────────────
  if (bpm > 0 && now - lastHeartPulse >= (unsigned long)(60000 / bpm)) {
    lastHeartPulse = now;
    heartBig = !heartBig;
  }

  // ── BLE send @ 500ms ──────────────────────────────────────────────────────
  if (now - lastBLESend >= 500 && deviceConnected) {
    lastBLESend = now;
    char buf[100];
    snprintf(buf, sizeof(buf),
      "{\"b\":%d,\"h\":%.1f,\"d\":%.1f,\"t\":%.1f,\"c\":%d,\"f\":%d}",
      bpm, sdnn, drowsinessScore, tiltAngle, calibDone ? 1 : 0, fingerOn ? 1 : 0);
    pSensorChar->setValue(buf);
    pSensorChar->notify();
  }

  // ── Display update @ 500ms ────────────────────────────────────────────────
  if (now - lastDisplayUpdate >= 500) {
    lastDisplayUpdate = now;
    drawBPM(bpm);
    drawHRV(sdnn);
    drawDrowsy(drowsinessScore);
    drawGPS(phoneLat, phoneLng, phoneSpeed);
    drawSpeed(phoneSpeed);
    drawCalibBar(now);
    drawFingerStatus();
  }

  drawECGSample(irValue);
  drawHeartAnim();

  delay(18);
}

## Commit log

2026-07-26 Initial commit: ESP32-C3 smartwatch firmware, Android app, and docs
2026-07-26 Add 3D-printed case and wristband models with preview renders
    [watchcase_new.3mf]
